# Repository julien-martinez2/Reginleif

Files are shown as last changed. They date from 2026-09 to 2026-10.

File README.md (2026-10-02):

# 🕷️ Reginleif — Autonomous Quadruped Walking Robot


[]()
[]()
[]()


> A custom-engineered, distributed quadruped combat walker inspired by the **XM2 Reginleif** and **M1A4 Juggernaut** from the acclaimed light novel & anime series ***86 - Eighty Six***.

---

## 📖 Table of Contents

- [Motivation & Inspiration](#-motivation--inspiration)
- [System Architecture](#-system-architecture)
  - [Functional Architecture](#functional-architecture)
  - [Technical & Electrical Architecture](#technical--electrical-architecture)
- [Hardware & Key Components](#-hardware--key-components)
  - [Sun Board (Central Controller)](#sun-board)
  - [Planet Boards (Legs Controllers)](#planet-boards)
  - [Moon Boards (Angle Sensors)](#moon-boards)
  - [Dual-Encoder Sensing Strategy](#dual-encoder-sensing-strategy)
- [Firmware Architecture](#-firmware-architecture)
  - [NVIC Preemptive Priority Hierarchy](#nvic-preemptive-priority-hierarchy)
  - [Real-Time Timer Scheduling](#real-time-timer-scheduling)
  - [Zero-CPU UART DMA with IDLE Line Detection](#zero-cpu-uart-dma-with-idle-line-detection)
- [Project Documentation & CAD Assets](#-project-documentation--cad-assets)
- [Roadmap & Deliverables](#-roadmap--deliverables)
- [Author & Community](#-author--community)
- [License](#-license)

---

## 💡 Motivation & Inspiration

The goal of this project is to take the agility, distinctive gait mechanics, and rugged aesthetic of the **XM2 Reginleif** from *86 - Eighty Six* and bring it into physical reality.

Building a multi-jointed legged walker from scratch serves as an end-to-end engineering challenge across multiple disciplines:
1. **Developing Real-Time Embedded Skills:** Mastering bare-metal ARM Cortex-M control, deterministic task scheduling, multi-bus SPI synchronization, and DMA streaming.
2. **Custom PCB & Power Electronics:** Designing compact 4-layer PCBs, handling thermal dissipation, power distribution for 16 simultaneous DC gearmotors, and integrated eFuse circuit protection.
3. **Complex Kinematics & Robotics:** Solving 3D inverse kinematics, gait generation, and closed-loop position control with mechanical backlash compensation.

**Open Source Philosophy:** Advanced quadruped robotics often relies on expensive off-the-shelf smart actuators or proprietary platforms. By documenting every schematic, trade-off, calculation, and line of code, this repository aims to serve as a practical, open reference for robotics students, engineers, and hobbyists building their own legged systems.

---

## 🏛️ System Architecture

### Functional Architecture

The robot employs a **hierarchical distributed architecture**, offloading high-frequency motor control to dedicated microcontrollers while centralizing planning, telemetry, and stabilization:

```
                      ┌────────────────────────────────────────┐
                      │        High-Level Intelligence         │
                      │     Raspberry Pi (Vision, Autonomy)    │
                      └──────────────────┬─────────────────────┘
                                         │ SPI / UART
                                         ▼
                      ┌────────────────────────────────────────┐
                      │    Central Master MCU ("Sun Board")    │
                      │  • IMU Body Stabilization (BNO086)     │
                      │  • Power Distribution & Battery Monitor│
                      │  • Master Gait Coordinator             │
                      └──────────────────┬─────────────────────┘
                                         │
          ┌──────────────────────────────┼──────────────────────────────┐
          │ RS-485 Differential Bus      │ (Master-Slave Protocol)      │
          ▼                              ▼                              ▼
 ┌──────────────────┐           ┌──────────────────┐           ┌──────────────────┐
 │  Planet Board 1  │           │  Planet Board 2  │           │ Planet Boards 3-4│
 │ (STM32G031)      │           │ (STM32G031)      │           │  (STM32G031)     │
 │ 4x N20 Motors    │           │ 4x N20 Motors    │           │ 4x N20 Motors    │
 └──────────────────┘           └──────────────────┘           └──────────────────┘
          │                     SPI Bus  │ (Master-Slave Protocol)      │
          ▼                              ▼                              ▼
 ┌──────────────────┐           ┌──────────────────┐           ┌──────────────────┐
 │ Moon Boards 1-4  │           │ Moon Boards 5-8  │           │ Moon Boards 9-16 │
 │ (MA730 Abs.)     │           │ (MA730 Abs.)     │           │ (MA730 Abs.)     │
 └──────────────────┘           └──────────────────┘           └──────────────────┘

```

---

### Technical & Electrical Architecture

```
                              [ 3S LiPo Battery (11.1V - 12.6V) ]
                                              │
                                              ▼
                                 [ TPS259827 15A eFuse ]
                                (UVLO Cutoff at 10.83V)
                                              │
                  ┌───────────────────────────┼───────────────────────────┐
                  │ VM (12V) Motor Power      │                           │
                  ▼                           ▼                           ▼
        ┌───────────────────┐       ┌───────────────────┐       ┌──────────────────────┐
        │ AP63205 (5V Buck) │       │ AP63203 (3.3V)    │       │ TPS22919 Load SW     │
        │ -> Raspberry Pi   │       │ -> Sun Board MCU  │       │ -> Planet Board VDD  │
        └───────────────────┘       └───────────────────┘       └─────────┬────────────┘
                                                                          │
                                  ┌───────────────────────────────────────┘
                                  │ 5-Pin JST-PA Harness (12V, 3.3V, GND, RS485_A/B)
                                  ▼
         ┌─────────────────────────────────────────────────────────────────┐
         │                     MODULAR PLANET BOARD (x4)                   │
         │                                                                 │
         │   [ THVD1406 RS-485 ] <── UART DMA ──> [ STM32G031 MCU ]        │
         │                                              │                  │
         │              ┌───────────────────────────────┴────────┐         │
         │              ▼ (SPI1 Bus)                             ▼ (SPI2)  │
         │     [ 4x MA730 Encoders ]                       [ DRV8908 ]     │
         │     Absolute Joint Angles                   8x Half-Bridges     │
         │     (Diametric Magnets)                               │         │
         │              ▲                                        ▼         │
         │              │ Joint Output Shaft              4x CHF-GW12T-N20 │
         │              └──────────────────────────────── (302:1 Worm)     │
         │                                                       │         │
         │   [ Incremental Encoders ] <── EXTI (PA0, PB1, PB3, PC14) ─────┘│
         └─────────────────────────────────────────────────────────────────┘

```

---

## 🛠️ Hardware & Key Components

### Sun Board
- **Master Processing:** STM32G031 / Raspberry Pi pairing for autonomous operation, telemetry streaming, and wireless communication.
- **Power & Circuit Protection:**
  - **TPS259827 15A eFuse:** Ultra-fast short-circuit protection and hardware programmable undervoltage lockout (V_UVLO = 10.83 V), preventing 3S LiPo over-discharge).
  - **AP63205 & AP63203:** High-efficiency synchronous buck converters generating 5 V (logic/SBC) and 3.3 V (peripherals).
  - **TPS22919 Load Switches:** Independent hardware-level logic power isolation and current limiting for each peripheral board.
- **Inertial Measurement:** **BNO086** 9-axis sensor fusion IMU over SPI for real-time body attitude stabilization.

### Planet Boards
- **Dedicated MCU:** **STM32G031G8U6** (ARM Cortex-M0+ running at 16 MHz, 4-layer compact layout with solid internal ground planes).
- **Motor Driver:** **DRV8908** automotive-grade 8 half-bridge driver, providing 4 fully independent bi-directional motor channels with individual hardware current limiting and fault telemetry.
- **Bus Transceiver:** **THVD1406DR** RS-485 transceiver with auto-direction sensing, eliminating the need for half-duplex DE/RE switching overhead.
- **Connectors:** JST-PA (power and differential communication) and JST-ZH (motor and sensor interconnects).

### Moon Boards
- **Angle Sensor:** MA730 is a magnetic angle sensor, which is placed next to the shaft of the motor on which a magnet is put.
- **Connectors:** JST-ZH (same as the motors).

---

### Dual-Encoder Sensing Strategy

Miniature worm gearboxes provide high stall torque and self-locking capabilities, but introduce mechanical backlash. To solve this, a dual-encoder feedback architecture is implemented:

| Sensor Type | Part & Interface | Resolution | Placement | Role in Control Loop |
| :--- | :--- | :--- | :--- | :--- |
| **Incremental Magnetic Encoder** | 2-Phase Hall (EXTI) | 2x Quadrature (~2107 counts/rev on motor shaft) | Motor Tail Shaft | **High-frequency velocity estimation** and instantaneous PID rate control. |
| **Absolute Magnetic Encoder** | **MA730GQ-Z** (SPI1) | 14-bit (16,384 counts/rev) | Output Joint Shaft (with Diametric Ring Magnets) | **Absolute angle calibration (10 Hz)** to eliminate gearbox play, backlash, and drift. |

---

## 💻 Firmware Architecture

### NVIC Preemptive Priority Hierarchy

The Cortex-M0+ interrupt controller is prioritized to guarantee that critical hardware signals and high-speed encoder transitions are never delayed by slower math computations:

```

Priority 0 (Highest) ──► SysTick & EXTI Lines (PA0, PB1, PB3, PC14, PA2 nFAULT)
│
Priority 1             ──► USART1 Communication & DMA Channels
│
Priority 2             ──► TIM2 (DRV8908 SPI Updates) & TIM3 (MagAlpha SPI Reads)
│
Priority 3 (Lowest)    ──► TIM1 (Software Inverse Kinematics & PID Loops)

```

- **Zero-Jitter Pulse Counting:** Encoders run at Priority 0 so wheel pulses are captured without dropped ticks during motor acceleration.
- **Fault Handling:** The open-drain `nFAULT` pin on `PA2` triggers an immediate shutdown sequence on overcurrent or thermal warnings.
- **Safe Preemption:** Heavy inverse kinematics floating-point calculations (Priority 3) safely yield execution whenever a peripheral event occurs.

---

### Real-Time Timer Scheduling

| Timer | Execution Frequency | Period | Task Description |
| :--- | :--- | :--- | :--- |
| **EXTI Lines** | Asynchronous | < 1 µs | Hardware edge-triggered incremental encoder decoding (Motors 1–4). |
| **TIM3** | **10 Hz** | 100 ms | SPI1 sequential polling of the 4 joint-level MA730 absolute encoders. |
| **TIM2** | **50 Hz** | 20 ms | SPI2 multi-channel register write updating DRV8908 motor PWM/directions. |
| **TIM1** | **20 Hz - 50 Hz** | 20 - 50 ms | Inverse kinematics trajectory solving, PID position/velocity loop execution. |

---

### Zero-CPU UART DMA with IDLE Line Detection

Communication between the central master board and the leg modules uses DMA combined with hardware IDLE line detection (`HAL_UARTEx_ReceiveToIdle_DMA`):

```cpp
// Non-blocking packet reception
void HAL_UARTEx_RxEventCallback(UART_HandleTypeDef *huart, uint16_t Size) {
    if (huart->Instance == USART1) {
        // Validate header and packet checksum
        if (Size >= 11 && rx_buffer[0] == 0xAA && rx_buffer[1] == 0x55) {
            ParseMasterCommand(rx_buffer, Size);
        }
        // Immediately re-arm DMA reception for the next packet
        HAL_UARTEx_ReceiveToIdle_DMA(&huart1, rx_buffer, RX_BUFFER_SIZE);
    }
}

```

* **Zero CPU overhead** while bytes are on the wire.
* The MCU triggers a single interrupt only after an entire variable-length packet is delivered and the bus goes idle.

---

## 📂 Project Documentation & CAD Assets

All schematics, BOMs, mechanical studies, and test records are available in the repository:

* **Hardware Schematics & KiCad Layouts:** 4-layer Leg Board, Satellite Angle Sensor PCBs, and Central Carrier Board.
* **Mechanical CAD:** 3D printed joint housings, worm gearbox mounts, and chassis brackets.

---

## 🗺️ Roadmap & Deliverables

* [x] Functional specification and torque/power feasibility study
* [x] 4-layer Leg Board PCB design and component assembly (KiCad)
* [ ] Mechanical Design and 3D-printing (FreeCAD)
* [ ] Bare-metal firmware setup (CubeMX, SPI1/SPI2, multi-channel EXTI, UART DMA)
* [ ] MA730 absolute magnetic sensor driver (`magalpha.cpp`)
* [ ] DRV8908 8 half-bridge motor controller driver (`drv8908.cpp`)
* [ ] 3D Inverse Kinematics math library and body orientation matrix
* [ ] Dynamic walking gait generation (Crawl, Trot, and Creep gaits)
* [ ] Central Sun Board assembly & BNO086 IMU stabilization loop
* [ ] Auxiliary subsystems: Tilt-axis turret mechanism and deployable anchor system

---

## 👤 Author & Community

Designed and engineered with passion by **Julien Martinez** ([@julien-martinez2](github.com/julien-martinez2)).

If you are working on custom quadruped walkers, legged robotics, or distributed motor controllers, feel free to open an issue, start a discussion, or contribute!

---

## 📄 License

This project is distributed under the **MIT License**. See [`LICENSE`](https://www.google.com/search?q=LICENSE) for more details.

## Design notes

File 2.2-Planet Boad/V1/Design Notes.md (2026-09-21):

# Planet Board V1 Design Notes

This board is designed to control 4 motors and get both their displacement with high-precision and absolute position.

The Planet Board has components on both sides, with power on top and logic on bottom.

To have this, all components are SMD.

### Power Supply

There is no power conversion in the Planet Boards, both the high and low voltage come from the Sun Board. This is to make the architecture easier and PCB surface smaller, even if this reduces the modularity of the board.

This works because the distance between the boards is very short, if it were important the voltage drop on the 3.3V rail would prevent this architecture.

### STM32

The model used is a STM32G031G8U6.

The specifications of this model has are : 

6 timers

2 SPI bus

2 UART bus

Real-Time Clock

28 pins including 26 GPIO and 15 ADC channels

14 External Interrupts (not on all pins) with 4 levels

Low-power modes

64 MHz CPU frequency

A useful function of STM32s here is that they can program, reset and boot each other via UART.

The Sun Board still includes a 4-pin header to program via SWD

Finally, some pins are compatible with 5V (reception only), which are nice to make the architecture even more modular.

### Sun Board Connexion

The Planet Boards don't include a resistor because of the topology, but also to make the legs as simple as Plug \& Play.

The connectors used are the same as in the Sun Board, JST-PA with reinforcement.

### Motors

The motors used in the first version of the project are CHF-GW12T-N20VA, N20 motors with worm gearboxes and incremental encoders.

The motors come with JST-ZH connectors, so the same are used on the PCB.

These motors stall at 0.4A (3.0kg/cm), and are rated at 0.15A (0.9kg.cm). Their nominal voltage is 12V for power and 3.3V or 5V for the encoders.

### Motors Driver

The motors driver used is a DRV8908, which can control up to 8 Half-Bridge (4 DC motors).

The rated current and voltage for each channel is much higher than the PCBs and the motors themselves at 1A per channel, and up to 40V.

It has a low-power mode, same as the STM32, though it can't control the HBs in this state.

The interface with the STM32 is an SPI bus.

The minimum PWM frequency for N20 motors is 400 Hz and the DRV is able to generate 2000 Hz

Finally, it has an nFAULT pin and an Open-Load Detection which monitor the motors state.

It also has undervoltage, overvoltage and overcurrent protection but these won't be useful here.

### Absolute Encoders

Since the motors only have incremental encoders, an absolute encoder is used to update the absolute position regularly.

This absolute encoder is put on the Moon Board which is placed right next to the motor shaft, improving modularity in case the motor model is changed.

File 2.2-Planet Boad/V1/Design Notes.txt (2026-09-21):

Sun Board V1 Design Notes

This board is designed to distribute power and supervise up to 5 Planet Boards by communicating via UART.
It has an SPST switch to power ON/OFF the whole robot.

Power Supply
The maximum voltage in the robot is 12.6V (LiPo 3S battery), so all the components on the power rail are rated for 25V or more.

The maximum current pulled by the robot is around 8A (considering that all the motors are stalling, which shouldn't happen and some software protections will be used). 
The Sun Board can handle up to 15A on the power rail, 2A for the 5V rail (RPI) and 2A for the 3.3V rail.

The eFuse used is a TPS259827, with the following configuration:
Undervoltage protection at 11V to protect the battery
Circuit Breaker at 15A
Current monitoring giving analog value from 0 to 2.97V (0 to 15A)
Lowest slew rate (0.68V/ms)

STM32
The model used is a STM32G031G8U6, same as the Planet Boards to keep the BOM consistent.
The specifications of this model has are : 
6 timers
2 SPI bus
2 UART bus
Real-Time Clock
28 pins including 26 GPIO and 15 ADC channels
14 External Interrupts (not on all pins) with 4 levels
Low-power modes
64 MHz CPU frequency

A useful function of STM32s here is that they can program, reset and boot each other via UART.

The Sun Board still includes a 4-pin header to program via SWD

Finally, some pins are compatible with 5V (reception only), which are nice to make the architecture even more modular.

Planet Board Connexion
The Sun Board is connected to the Planet Boards via 5 wires :
- 3.3V
- VCC
- GND
- TX
- RX

Since each Planet Board can pull up to 2A, the connectors and wires are sized for a 3A constant load.

The Sun Board's STM32 communicates with the Planet Boards' STM32s via UART.
Only one resistor is used on the Sun Board to keep a modular structure and since the architecture is closer to a Star topology than a Chain one 

BNO085
To balance the robot, a BNO085 is used as is has almost no drift.
The communication to the STM32 is done via SPI bus.

RPI Zero 2 W
The RPI handles the communication to the computer and camera feedback.
It rests on a female pin header and M2 standoffs and communicates with the STM32 via UART.

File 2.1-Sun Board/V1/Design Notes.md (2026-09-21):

# Sun Board V1 Design Notes

This board is designed to distribute power and supervise up to 5 Planet Boards by communicating via UART.

It has an SPST switch to power ON/OFF the whole robot.

The Sun Board has components on both sides, same as the Planet Board, with logic on top and power on bottom.

To have this, all components are SMD, apart from the battery connector which is soldered manually in a hole.

### Power Supply

The maximum voltage in the robot is 12.6V (LiPo 3S battery), so all the components on the power rail are rated for 25V or more.

The maximum current pulled by the robot is around 8A (considering that all the motors are stalling, which shouldn't happen and some software protections will be used). 

The Sun Board can handle up to 15A on the power rail, 2A for the 5V rail (RPI) and 2A for the 3.3V rail.

The eFuse used is a TPS259827, with the following configuration:

* Undervoltage protection at 11V to protect the battery
* Circuit Breaker at 15A
* Current monitoring giving analog value from 0 to 2.97V (0 to 15A)
* Lowest slew rate (0.68V/ms)

### STM32

The model used is a STM32G031G8U6, same as the Planet Boards to keep the BOM consistent.

The specifications of this model has are : 

* 6 timers
* 2 SPI bus
* 2 UART bus
* Real-Time Clock
* 28 pins including 26 GPIO and 15 ADC channels
* 14 External Interrupts (not on all pins) with 4 levels
* Low-power modes
* 64 MHz CPU frequency

A useful function of STM32s here is that they can program, reset and boot each other via UART.

The Sun Board still includes a 4-pin header to program via SWD

Finally, some pins are compatible with 5V (reception only), which are nice to make the architecture even more modular.

### Planet Board Connexion

The Sun Board is connected to the Planet Boards via 5 wires :

\- 3.3V

\- VCC

\- GND

\- TX

\- RX

Since each Planet Board can pull up to 2A, the connectors and wires are sized for a 3A constant load.

The connector used are JST-PA with reinforcement.

The Sun Board's STM32 communicates with the Planet Boards' STM32s via UART.

Only one resistor is used on the Sun Board to keep a modular structure and since the architecture is closer to a Star topology than a Chain one

### BNO085

To balance the robot, a BNO085 is used as is has almost no drift.

The communication to the STM32 is done via SPI bus.

### RPI Zero 2 W

The RPI handles the communication to the computer and camera feedback.

It rests on a female pin header and M2 standoffs and communicates with the STM32 via UART.

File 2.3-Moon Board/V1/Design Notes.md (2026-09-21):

# Moon Board V1 Design Notes

This board is designed to get the absolute position of a single motor shaft. It sits right next to it on the motor in a side-shaft configuration (possible because they have worm gearboxes).

The components are only on one side and the PCB is basic, but to fabricate it along with the Sun and Planet boards it also has 4 layers.

### Connectors

The same connectors as the motors are used between the Planet and Moon board to simplify the BOM.

### Absolute Encoders

The absolute encoders used in this project are MagAlpha, an angle sensor measuring the magnetic field generated by a magnet fixed on the other side of the joint (so the shaft here).

The magnet is a diametric ring magnet, put on the joint around the shaft.

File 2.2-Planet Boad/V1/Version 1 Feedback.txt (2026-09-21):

Planet Board Version 1 

Goals: 
- The main goal of this board is to be able to control a whole leg with close control (4 motors and 4 angle sensors).
- The second goal is to make this board modular, which can be used in various robots (ie. RC car, drone, etc.).
- The third goal is to make the board as small as possible.

Feedback:
- The board lacks mounting pins
- The board lacks LEDs to show its state (3.3V, VCC, Motor driver fault)
- Lacks more silkscreen to avoid having to look at design files
- Lacks some protections (Local PTC fuse, TVS diode)
- Put two of the angle sensors (currently on the moon boards) directly on the planet board
- Add test pins since the chosen connectors can't be gripped, and even more the STM32
- Too many vias near the center of the board
- Power spread on the PCB

Most of these issues come from trying to make the board smaller.

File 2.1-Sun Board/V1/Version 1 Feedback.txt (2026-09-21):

Sun Board Version 1 

This board was designed after the Planet and Moon ones, and already resolves some of their issues.

Goals: 
- The main goal of this board is to be able to supervise up to 5 Planet Boards.
- The second goal is to make this board modular, which can be used in various robots (ie. RC car, drone, etc.).
- The third goal is to make the board as small as possible, but still big enough for an RPI Zero 2 W to fit on.

Feedback:
- The board uses the same mounting pins for the RPI and the mechanical structure
- The board lacks LEDs to show its state (3.3V, VCC, Planet Board load)
- Lacks more silkscreen to avoid having to look at design files
- Add test pins since the chosen connectors can't be gripped, so mainly the STM32, BNO085/86 and some connectors
- The chosen SPDT switch is too small

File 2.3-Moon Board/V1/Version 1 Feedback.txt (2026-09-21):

Moon Board Version 1 

Most of the goals and feedbacks of this board are the same as the Planet Board since they were both designed together.
I will only keep here what will be relevent after taking into account the feedback for the Planet Board.

Goals: 
- The main goal of this board is to be able to get the absolute angle of a motor shaft via a diametric ring magnet in side-shaft position.
- The second goal is to make this board modular, which can be used in various robots (ie. RC car, drone, etc.).
- The third goal is to make the board as small as possible.

Feedback:
- The board lacks mounting pins
- The board lacks LEDs to show its state (3.3V, VCC, Motor driver fault)
- Lacks more silkscreen to avoid having to look at design files
- Lacks some protections (Local PTC fuse, TVS diode)
- Add test pins since the chosen connectors can't be gripped, so only the MagAlpha here

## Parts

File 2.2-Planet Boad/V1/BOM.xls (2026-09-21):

PCBWay Bom Quotation, Product No.:
Item # | *Designator | *Qty | Manufacturer | *Mfg Part # | Description / Value | *Package/Footprint | Mounting Type | Your Instructions / Notes | *Unit Price(5 units) | *Total | *Delivery Time | *Actual Purchase Mfg Part # | *PCBWay Note | Customer Reply | PCBWay Update
1 | J1 | 5 | JST | SM05B-PASS-TBT | Connector Header Surface Mount, Right Angle 5 position 0.079" (2.00mm) | SMT 5P | SMD | Digikey or Chinese equivalent |  | $0.000
2 | J2 | 5 | Harwin | M20-7910442R | 4 Position Receptacle Connector 0.100 (2.54mm) Surface Mount, Right Angle Gold | SMT 4P | SMD | Digikey or Chinese equivalent |  | $0.000
3 | J3,J4,J5,J6,J7,J8,J9,J10 | 40 | JST | S6B-ZR-SM4A-TF | Connector Header Surface Mount, Right Angle 6 position 0.059 (1.50mm) | SMT 6P | SMD | Digikey or Chinese equivalent |  | $0.000
4 | U1 | 5 | STMicroelectronics | STM32G031G8U6 | ARM® Cortex®-M0+ STM32G0 Microcontroller IC 32-Bit 64MHz 64KB (64K x 8) FLASH 28-UFQFPN (4x4) | UFQFPN-28 | SMD | Digikey or Chinese equivalent |  | $0.000
5 | U2 | 5 | Texas Instruments | DRV8908QPWPRQ1 | Half Bridge (8) Driver DC Motors, General Purpose MOSFET (Metal Oxide) 24-HTSSOP | HTSSOP-24 | SMD | Digikey or Chinese equivalent |  | $0.000
6 | U3 | 5 | Texas Instruments | THVD1406DR | 1/1 Transceiver Half RS422, RS485 8-SOIC | SOIC | SMD | Digikey or Chinese equivalent |  | $0.000
8 | R1 | 5 | Panasonic | ERA-3ARW103V | RES, 10.0 k, 0.05%, 0.1 W, AEC-Q200 Grade 0, 0603 | 0603 | SMD | Digikey or Chinese equivalent |  | $0.000
9 | C5 | 5 | KEMET | T491X107K025AT | CAP, AL, 100 µF, 25 V, +/- 10%, 0.3 ohm, 2917 X SMD | CASE-X-7343-43 | SMD | Digikey or Chinese equivalent |  | $0.000
10 | C1 | 5 | Samsung | CL10B105KQ8NNNC | CAP, CERM, 1 uF, 6.3 V, +/- 10%, X7R, 0603 | 0603 | SMD | Digikey or Chinese equivalent |  | $0.000
11 | C2,C6,C7 | 15 | KEMET | C0603C104K9RAC7867 | CAP, CERM, 0.1 µF, 6.3 V,+/- 10%, X7R, 0603 | 0603 | SMD | Digikey or Chinese equivalent |  | $0.000
12 | C3,C4 | 10 | KEMET | C0603C104J5RACTU | CAP, CERM, 0.1 uF, 50 V, +/- 5%, X7R, 0603 | 0603 | SMD | Digikey or Chinese equivalent |  | $0.000
 |  |  |  |  |  |  |  |  | Component Cost | $0.00
 |  |  |  |  |  |  |  |  | Assembly Cost
 |  |  |  |  |  |  |  |  | PCB Cost
 |  |  |  |  |  |  |  |  | All Total 5 Units

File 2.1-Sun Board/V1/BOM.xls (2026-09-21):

PCBWay Bom Quotation, Product No.:
Item # | *Designator | *Qty | Manufacturer | *Mfg Part # | Description / Value | *Package/Footprint | Mounting Type | Your Instructions / Notes | *Unit Price(5 units) | *Total | *Delivery Time | *Actual Purchase Mfg Part # | *PCBWay Note | Customer Reply | PCBWay Update
1 | R1 | 1 | Würth Elektronik | 560112110033 | 1 MOhms ±1% 0.1W, 1/10W | SMD 0402 | SMD
2 | R2 | 1 | Würth Elektronik | 560112110190 | 113 kOhms ±1% 0.1W, 1/10W | SMD 0402 | SMD
3 | R3,R10 | 2 | Würth Elektronik | 560112110019 | 100 kOhms ±1% 0.1W, 1/10W | SMD 0402 | SMD
4 | R11 | 1 | YAGEO | RT0402BRD0733KL | 33 kOhms ±0.1% 0.063W, 1/16W | SMD 0402 | SMD
5 | R6,R8,R9 | 3 | Panasonic Industry | ERA-3ARW103V | 10 kOhms ±0.05% 0.1W, 1/10W | SMD 0603 | SMD
6 | R5 | 1 | Würth Elektronik | 560112110108 | 806 Ohms ±1% 0.1W, 1/10W | SMD 0402 | SMD
7 | R7 | 1 | Würth Elektronik | 560112110065 | 120 Ohms ±1% 0.1W, 1/10W | SMD 0402 | SMD
8 | R4 | 1 | Würth Elektronik | 560112110008 | 100 Ohms ±5% 0.1W, 1/10W | SMD 0402 | SMD
9 | C4,C5 | 2 | KEMET | T491X107K025AT | 100uF, 25V, 10% Tolerance | SMD 2917-X | SMD
10 | C13,C14,C17,C18,C19 | 5 | Samsung Electro-Mechanics | CL21A226KOQNNNG | 22 µF ±10% 16V Ceramic Capacitor X5R | SMD 0805 | SMD
11 | C11,C15 | 2 | Murata Electronics | GRT188R61E106ME13D | 10 µF ±20% 25V Ceramic Capacitor X5R | SMD 0603 | SMD
12 | C20,C21,C22,C23,C24 | 5 | Samsung Electro-Mechanics | CL05A105KO5NNNC | 1 µF ±10% 16V Ceramic Capacitor X5R | SMD 0402 | SMD
13 | C1,C2,C3,C7,C8,C9,C10,C12,C16,C25 | 10 | KEMET | C0603C104J5RACTU | 0.1 µF ±5% 50V Ceramic Capacitor X7R | SMD 0603 | SMD
14 | C6 | 1 | YAGEO | CC0402JRX7R9BB682 | 6800 pF ±5% 50V, X7R | SMD 0402 | SMD
15 | L1,L2 | 2 | Würth Elektronik | 74438357047 | 4.7 µH Shielded Molded Inductor 5.1 A 44mOhm Max | SMD 1616 | SMD
16 | J1 | 1 | Harwin Inc. | M20-7910442R | 4 Position Receptacle Connector 0.100" (2.54mm) | 4POS | SMD
17 | J2,J3,J4,J5,J6 | 5 | JST | SM05B-PASS-TBT | 5-pin, SMD, Right-Angle | 5POS | SMD
18 | J7 | 1 | Sullins Connector Solutions | NPTC202KFMS-RC | 40 Position Header Connector 0.100" (2.54mm) | 40POS | SMD
19 | S1 | 1 | E-Switch | EG1215AA | SWITCH SLIDE SPDT 25MA 24V | SMD, Right-Angle | SMD
20 | U1 | 1 | STMicroelectronics | STM32G031G8U6 | ARM® Cortex®-M0+ STM32G0 Microcontroller IC 32-Bit 64MHz 64KB (64K x 8) FLASH 28-UFQFPN (4x4) | SMD UFQFPN-28 | SMD
21 | U2 | 1 | Texas Instruments | TPS259824ONRGET | Electronic Fuse Regulator 15A | SMD 24-VQFN | SMD
22 | U3 | 1 | Texas Instruments | THVD1406DR | 1/1 Transceiver Half RS422, RS485 | SMD 8-SOIC | SMD
23 | U4 | 1 | CEVA Technologies, Inc. | BNO086 | Accelerometer, Gyroscope, Magnetometer, Temperature, 9 Axis Sensor I2C, SPI Output | SMD 28-TFLGA | SMD
24 | U5 | 1 | Diodes Incorporated | AP63203WU | Buck Switching Regulator IC Positive Fixed 3.3V 1 Output 2A | SMD TSOT23-6 | SMD
25 | U6 | 1 | Diodes Incorporated | AP63205WU | Buck Switching Regulator IC Positive Fixed 5V 1 Output 2A | SMD TSOT23-6 | SMD
26 | U7,U8,U9,U10,U11 | 5 | Texas Instruments | TPS22919DCKR | Power Switch/Driver 1:1 N-Channel 1.5A | SMD SC-70-6 | SMD
26
27
 |  |  |  |  |  |  |  |  | Component Cost | $0.00
 |  |  |  |  |  |  |  |  | Assembly Cost
 |  |  |  |  |  |  |  |  | PCB Cost
 |  |  |  |  |  |  |  |  | All Total 5 Units

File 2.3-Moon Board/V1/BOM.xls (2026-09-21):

PCBWay Bom Quotation, Product No.:
Item # | *Designator | *Qty | Manufacturer | *Mfg Part # | Description / Value | *Package/Footprint | Mounting Type | Your Instructions / Notes | *Unit Price(5 units) | *Total | *Delivery Time | *Actual Purchase Mfg Part # | *PCBWay Note | Customer Reply | PCBWay Update
3 | J11 | 1 | JST | S6B-ZR-SM4A-TF | Connector Header Surface Mount, Right Angle 6 position 0.059 (1.50mm) | SMT 6P | SMD | Digikey or Chinese equivalent |  | $0.000
7 | U4 | 1 | MPS | MA730GQ-P | Hall Effect Sensor Angle External Magnet | QFN-16 | SMD | Digikey or Chinese equivalent |  | $0.000
10 | C8 | 1 | Samsung | CL10B105KQ8NNNC | CAP, CERM, 1 uF, 6.3 V, +/- 10%, X7R, 0603 | 0603 | SMD | Digikey or Chinese equivalent |  | $0.000
 |  |  |  |  |  |  |  |  | Component Cost | $0.00
 |  |  |  |  |  |  |  |  | Assembly Cost
 |  |  |  |  |  |  |  |  | PCB Cost
 |  |  |  |  |  |  |  |  | All Total 5 Units

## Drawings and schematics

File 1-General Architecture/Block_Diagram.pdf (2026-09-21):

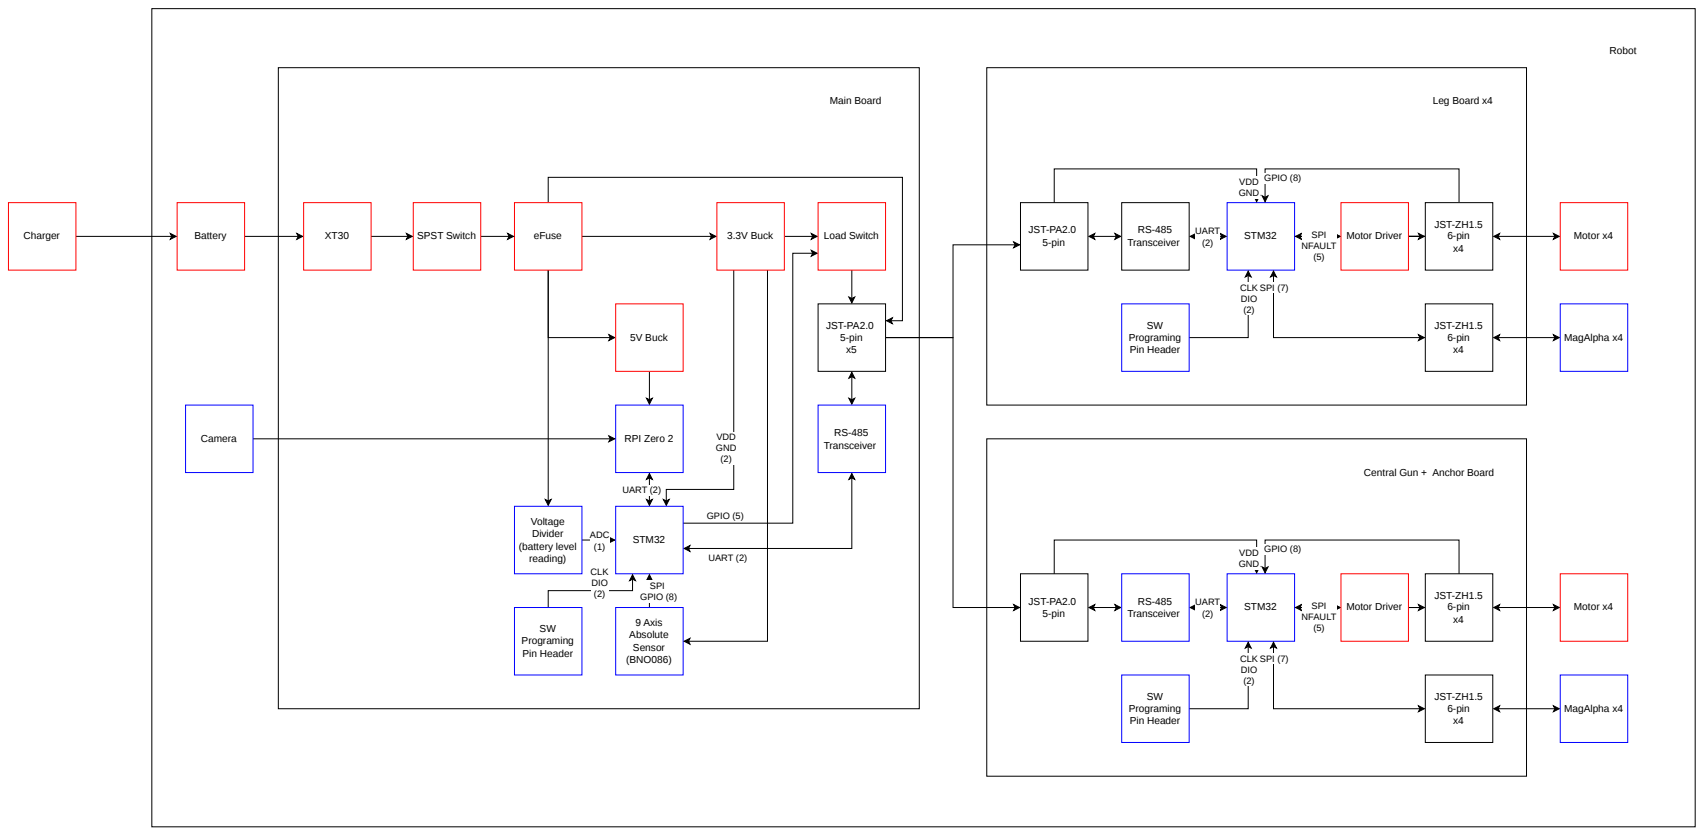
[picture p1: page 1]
Battery; eFuse; ADC (1); Voltage Divider (battery level reading); UAR; GPIO (5); VDD GND (2); STM32; JST-PA2.0 5-pin x5; Main Board; JST-PA2.0; 5-pin; SPI; NFAULT (5); GPIO (8); JST-ZH1.5 6-pin x4; Leg Board x4; Motor x4; VDD GND; RPI Zero 2; SPI GPIO (8); 9 Axis Absolute Sensor (BNO086); Camera; SPI (7); MagAlpha x4; Transceiver; Motor Driver; 5V Buck; RS-485 Transceiver; Charger; 3.3V Buck; CLK DIO (2); SW Programing Pin Header; SPST Switch; Robot; Load Switch

Central Gun + Anchor Board

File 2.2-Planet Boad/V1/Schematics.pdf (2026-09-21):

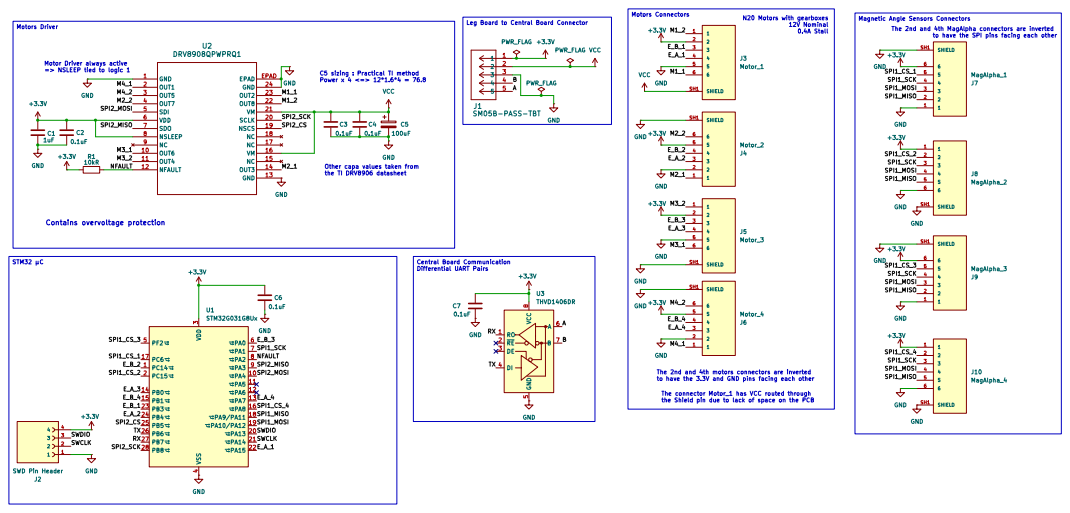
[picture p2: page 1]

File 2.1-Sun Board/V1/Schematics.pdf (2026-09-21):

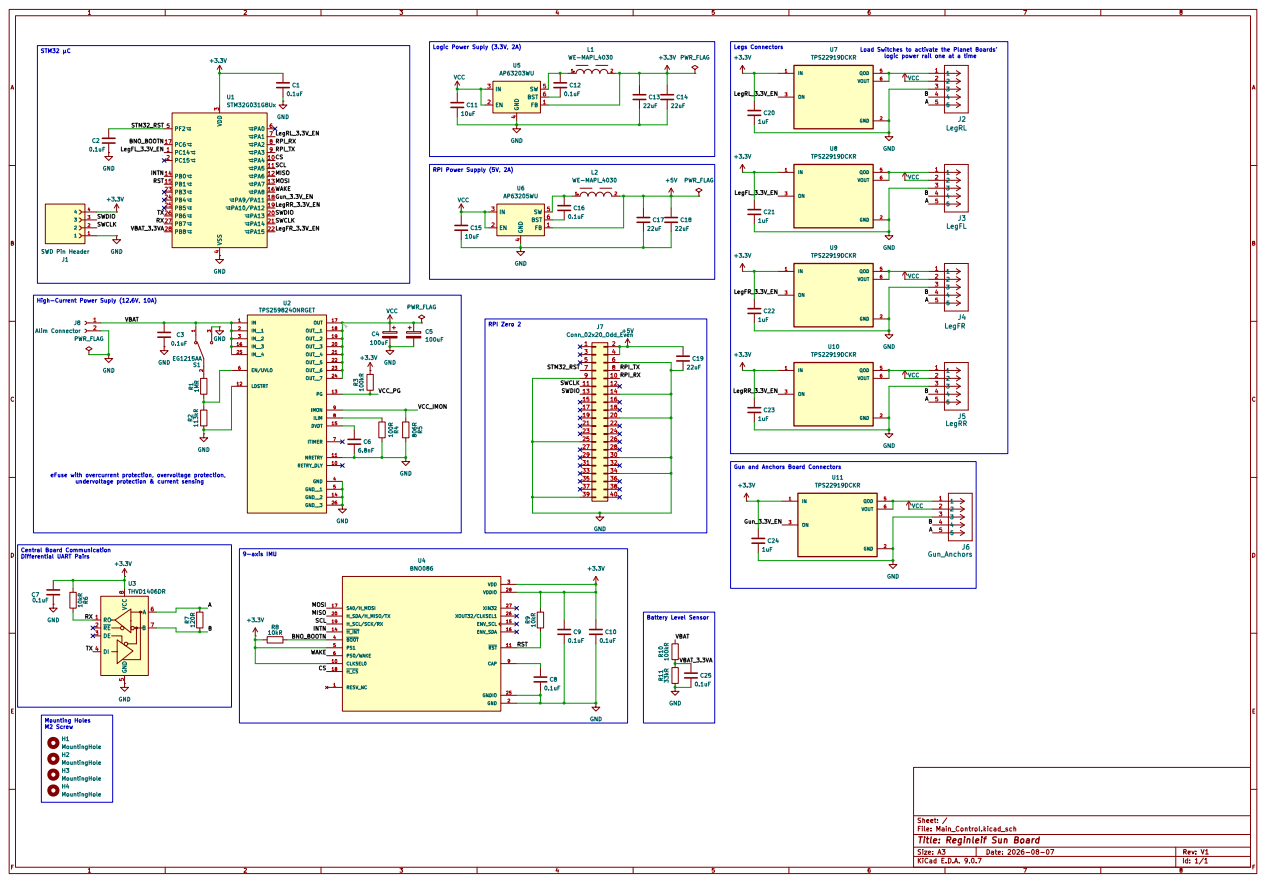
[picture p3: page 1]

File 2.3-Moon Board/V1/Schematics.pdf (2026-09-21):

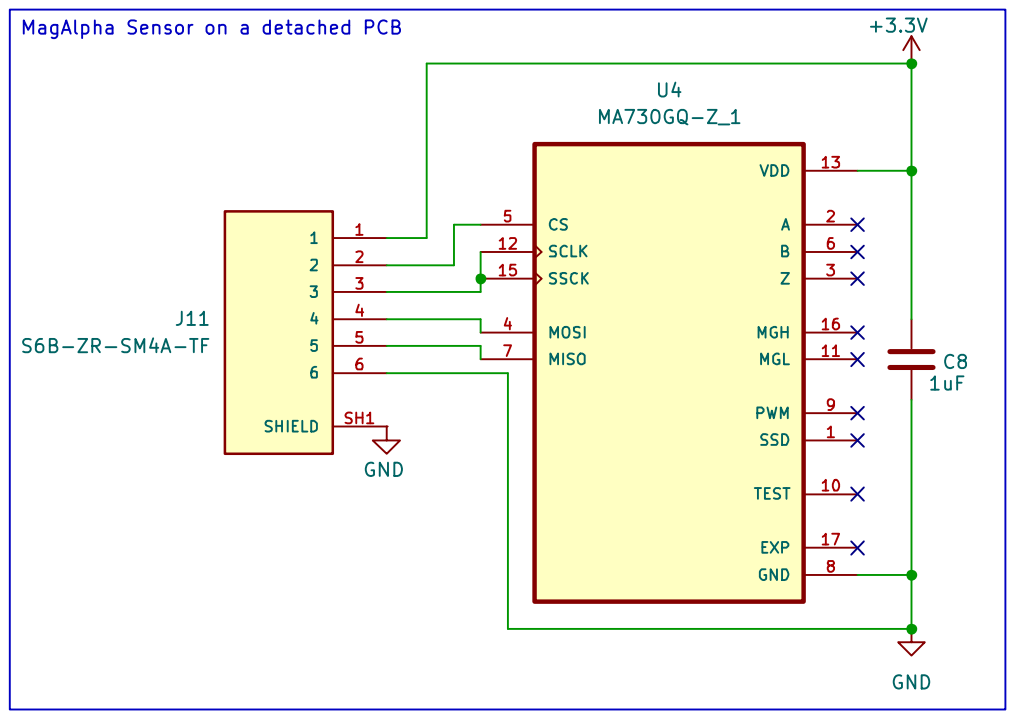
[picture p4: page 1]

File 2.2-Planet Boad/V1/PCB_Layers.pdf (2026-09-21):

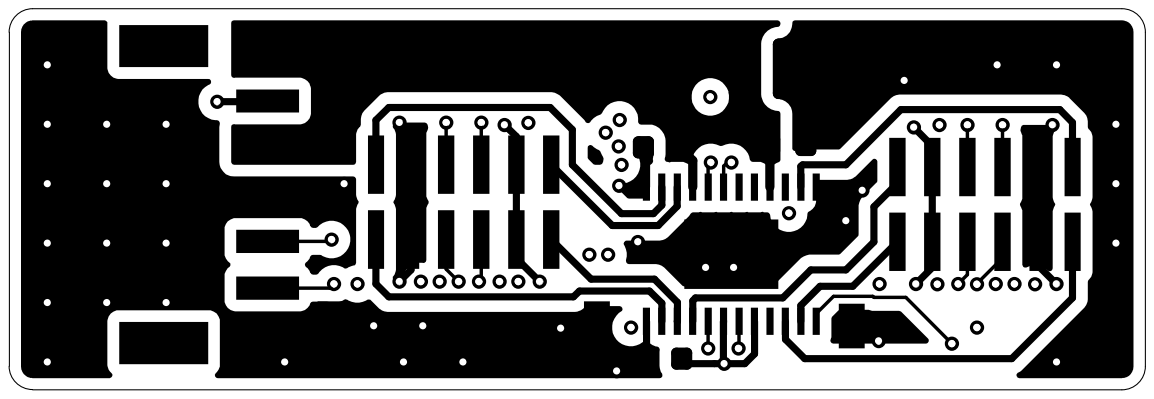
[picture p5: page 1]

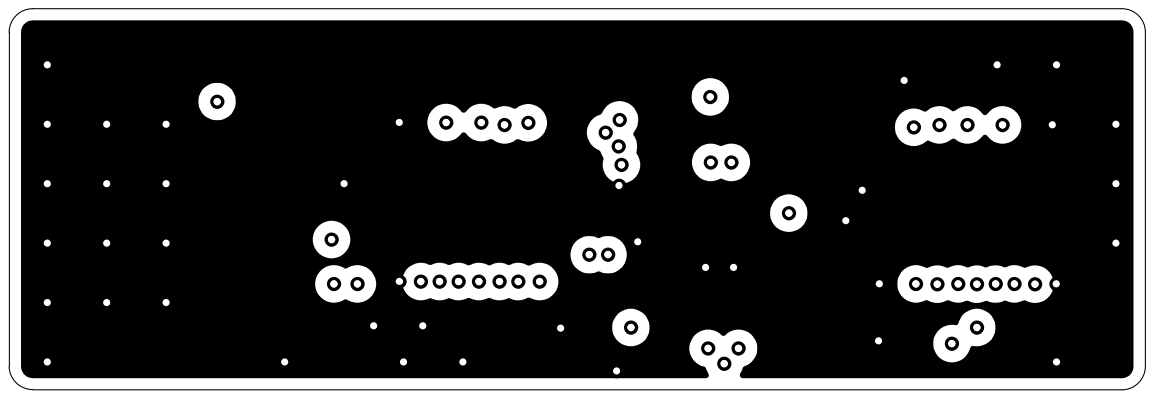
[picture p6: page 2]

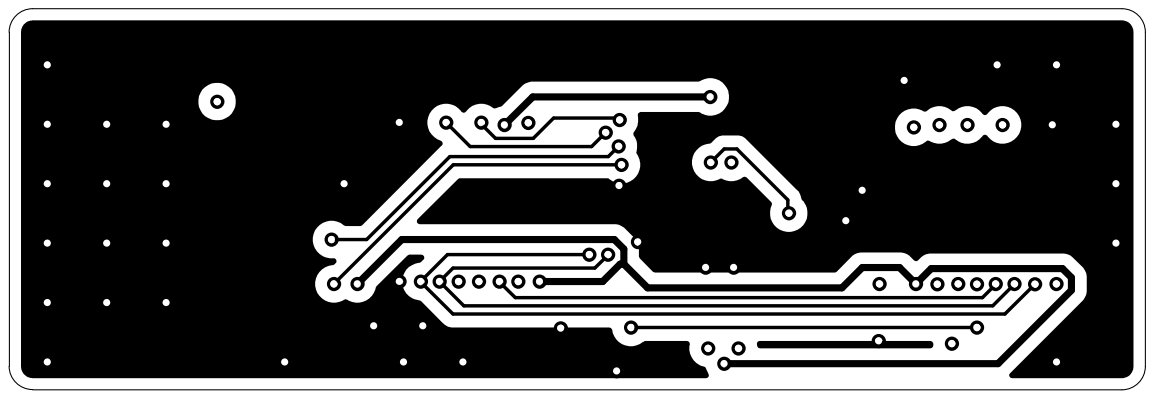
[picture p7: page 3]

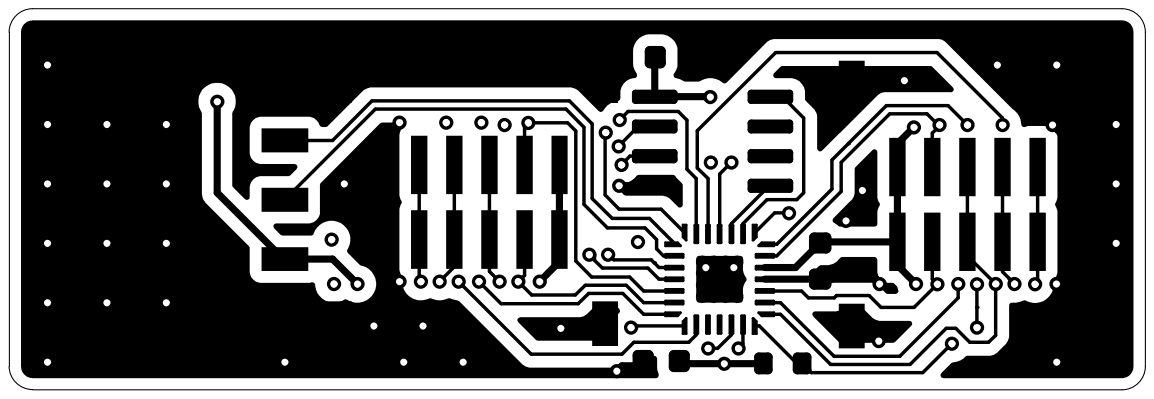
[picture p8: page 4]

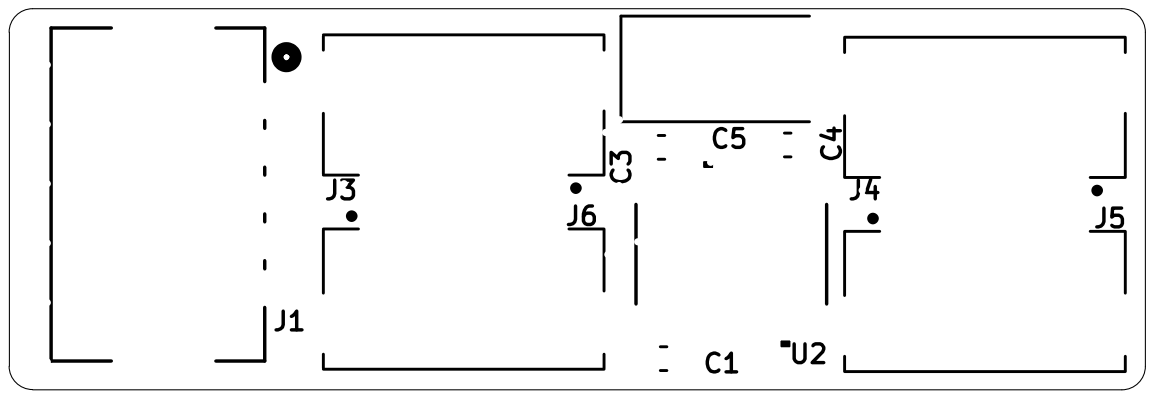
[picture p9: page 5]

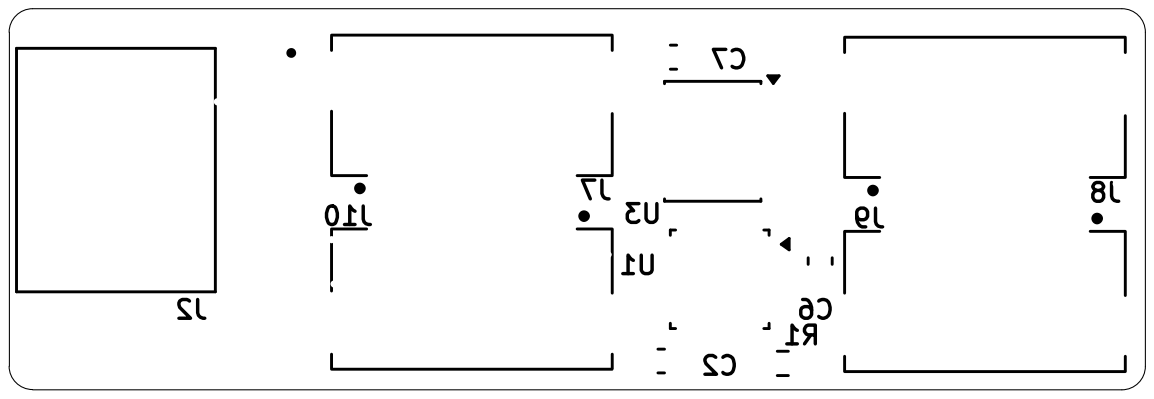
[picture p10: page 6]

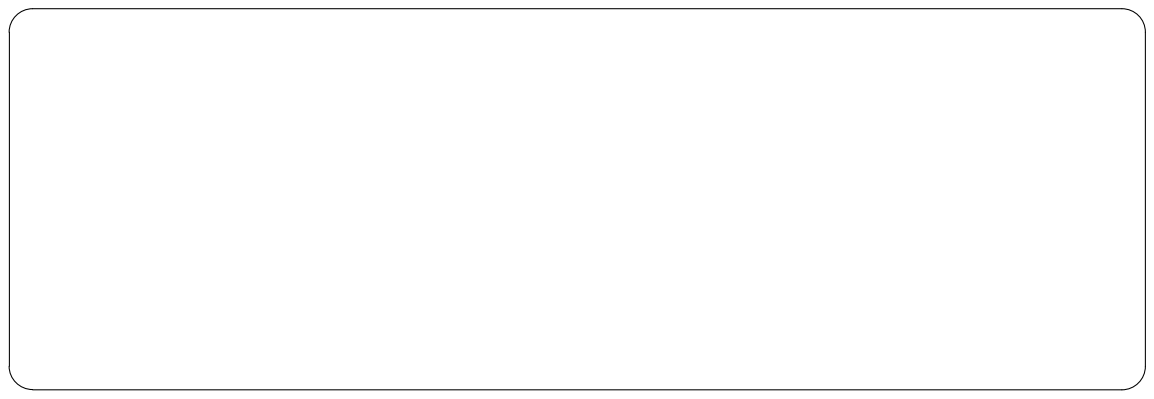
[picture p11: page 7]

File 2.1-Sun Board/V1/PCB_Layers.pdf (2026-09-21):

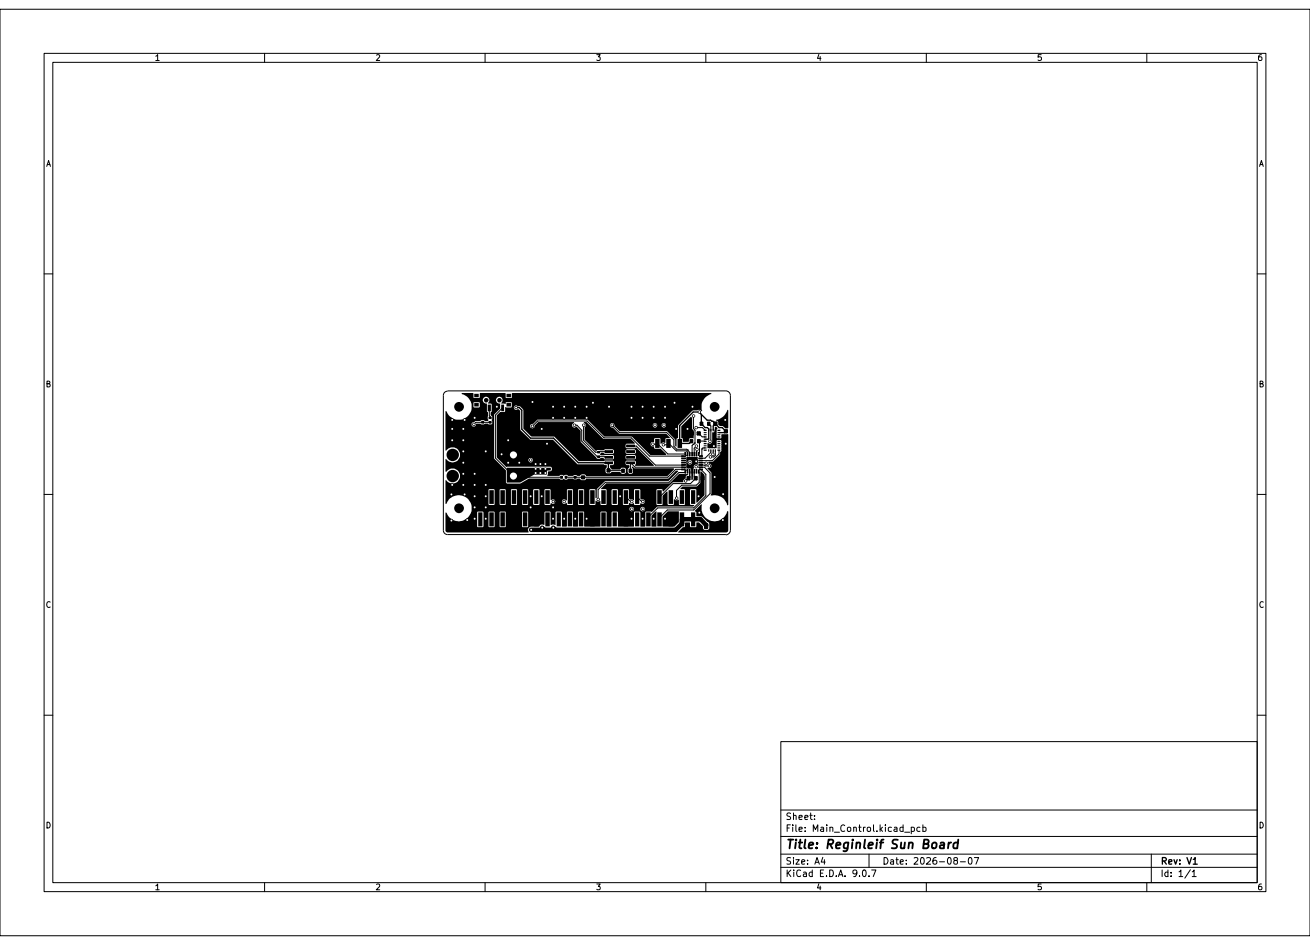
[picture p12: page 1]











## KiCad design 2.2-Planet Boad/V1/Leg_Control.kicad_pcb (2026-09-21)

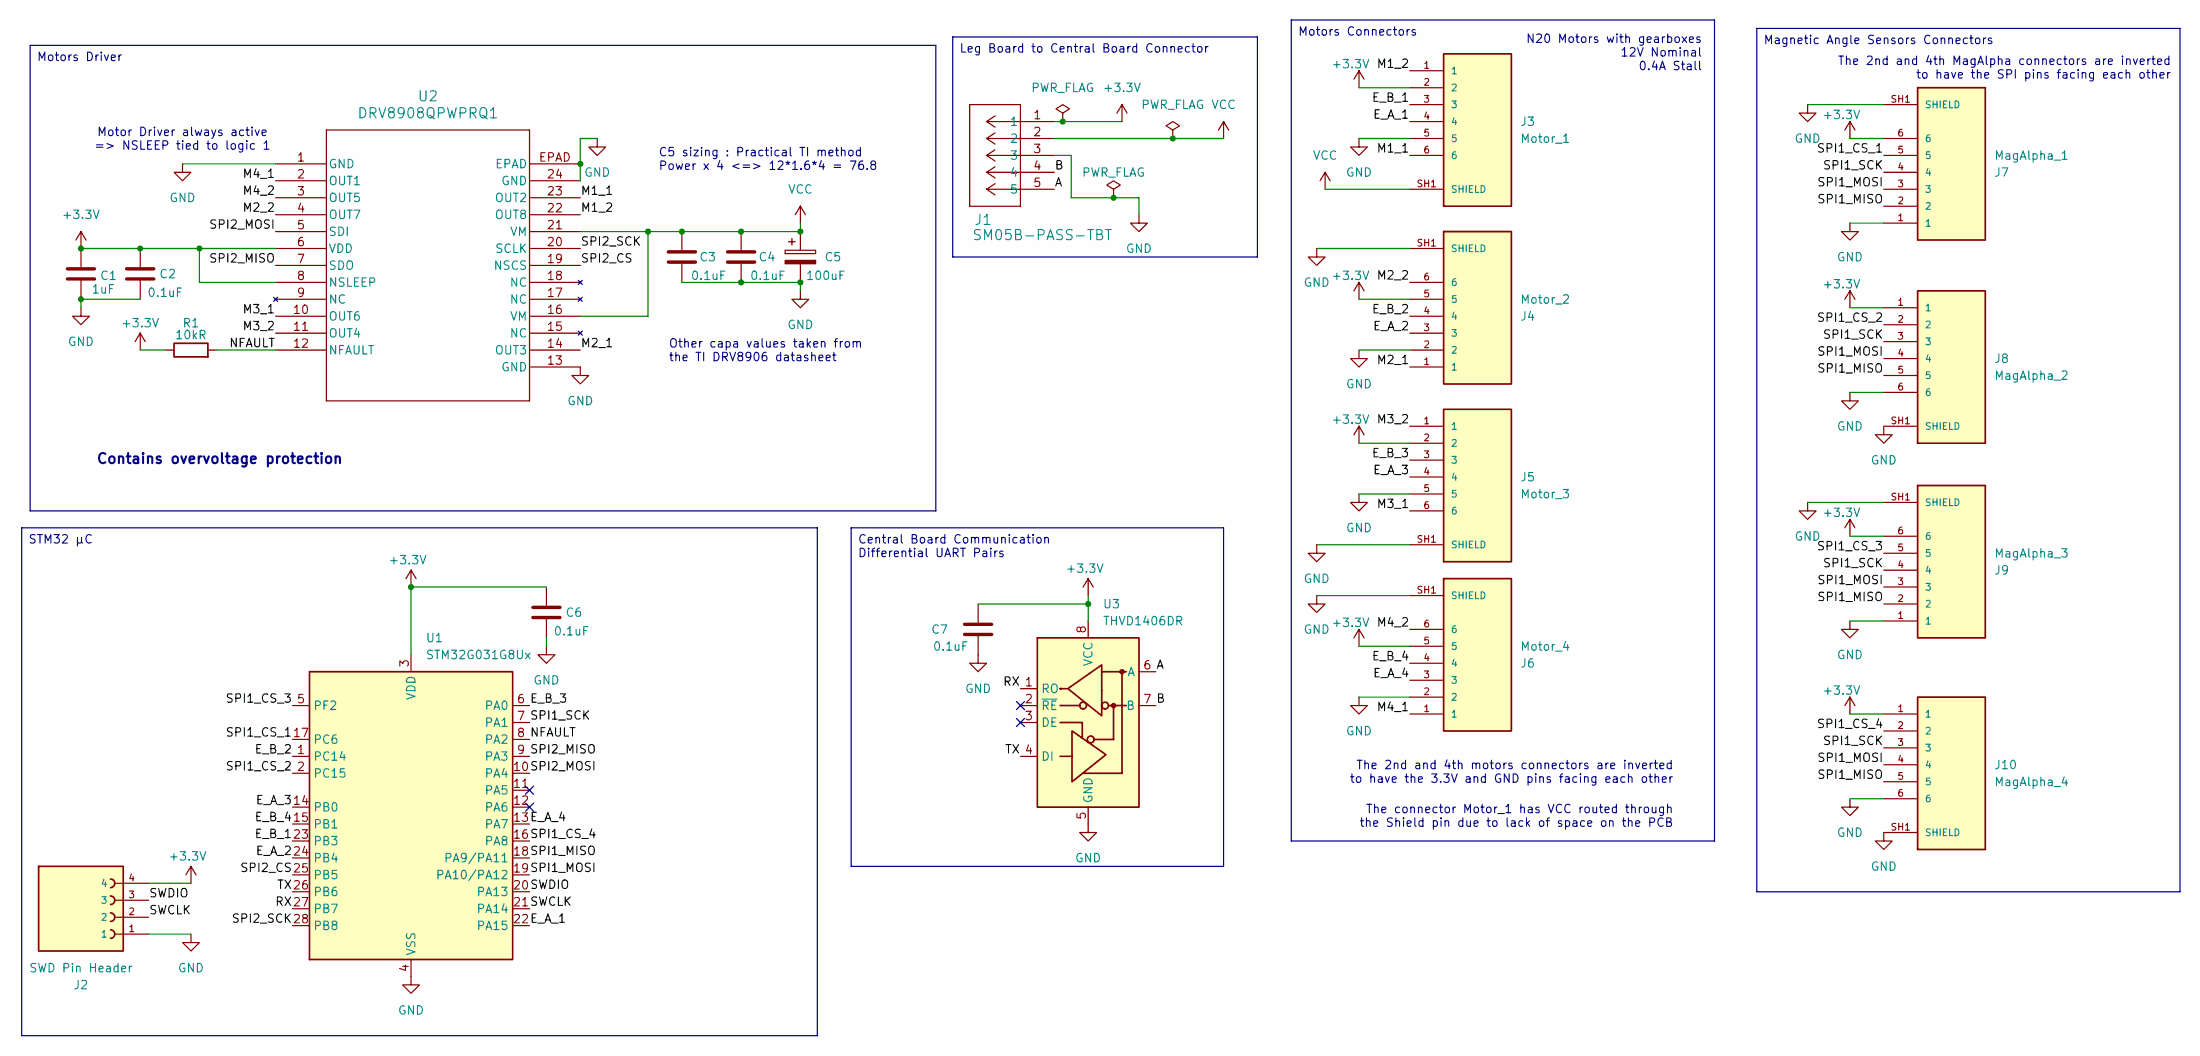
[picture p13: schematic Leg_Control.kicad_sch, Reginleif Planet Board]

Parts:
C1: 1uF; C_0603_1608Metric
C2, C3, C4, C6, C7: 0.1uF; C_0603_1608Metric
C5: 100uF; CP_EIA-7343-43_Kemet-X
J1: SM05B-PASS-TBT; SM05B_PASS
J2: SWD Pin Header; HARWIN_M20-7910442R
J3: Motor_1; JST_S6B-ZR-SM4A-TF_LF__SN_
J4: Motor_2; JST_S6B-ZR-SM4A-TF_LF__SN_
J5: Motor_3; JST_S6B-ZR-SM4A-TF_LF__SN_
J6: Motor_4; JST_S6B-ZR-SM4A-TF_LF__SN_
J7: MagAlpha_1; JST_S6B-ZR-SM4A-TF_LF__SN_
J8: MagAlpha_2; JST_S6B-ZR-SM4A-TF_LF__SN_
J9: MagAlpha_3; JST_S6B-ZR-SM4A-TF_LF__SN_
J10: MagAlpha_4; JST_S6B-ZR-SM4A-TF_LF__SN_
R1: 10kR; R_0603_1608Metric
U1: STM32G031G8Ux; QFN-28_4x4mm_P0.5mm
U2: DRV8908QPWPRQ1; PWP24_4P5X7P9_TEX-L
U3: THVD1406DR; SOIC-8_3.9x4.9mm_P1.27mm

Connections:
+3.3V: C1.1, C2.1, C6.1, C7.1, J1.1, J2.4, J3.2, J4.5, J5.2, J6.5, J7.6, J8.1, J9.6, J10.1, R1.1, U1.3 (VDD), U2.6 (VDD), U2.8 (NSLEEP), U3.8 (VCC)
/A: J1.5, U3.6 (A)
/B: J1.4, U3.7 (B)
/E_A_1: J3.4, U1.22 (PA15)
/E_A_2: J4.3, U1.24 (PB4)
/E_A_3: J5.4, U1.14 (PB0)
/E_A_4: J6.3, U1.13 (PA7)
/E_B_1: J3.3, U1.23 (PB3)
/E_B_2: J4.4, U1.1 (PC14)
/E_B_3: J5.3, U1.6 (PA0)
/E_B_4: J6.4, U1.15 (PB1)
/M1_1: J3.6, U2.23 (OUT2)
/M1_2: J3.1, U2.22 (OUT8)
/M2_1: J4.1, U2.14 (OUT3)
/M2_2: J4.6, U2.4 (OUT7)
/M3_1: J5.6, U2.10 (OUT6)
/M3_2: J5.1, U2.11 (OUT4)
/M4_1: J6.1, U2.2 (OUT1)
/M4_2: J6.6, U2.3 (OUT5)
/NFAULT: R1.2, U1.8 (PA2), U2.12 (NFAULT)
/RX: U1.27 (PB7), U3.1 (RO)
/SPI1_CS_1: J7.5, U1.17 (PC6)
/SPI1_CS_2: J8.2, U1.2 (PC15)
/SPI1_CS_3: J9.5, U1.5 (PF2)
/SPI1_CS_4: J10.2, U1.16 (PA8)
/SPI1_MISO: J7.2, J8.5, J9.2, J10.5, U1.18 (PA9/PA11)
/SPI1_MOSI: J7.3, J8.4, J9.3, J10.4, U1.19 (PA10/PA12)
/SPI1_SCK: J7.4, J8.3, J9.4, J10.3, U1.7 (PA1)
/SPI2_CS: U1.25 (PB5), U2.19 (NSCS)
/SPI2_MISO: U1.9 (PA3), U2.7 (SDO)
/SPI2_MOSI: U1.10 (PA4), U2.5 (SDI)
/SPI2_SCK: U1.28 (PB8), U2.20 (SCLK)
/SWCLK: J2.2, U1.21 (PA14)
/SWDIO: J2.3, U1.20 (PA13)
/TX: U1.26 (PB6), U3.4 (DI)
GND: C1.2, C2.2, C3.2, C4.2, C5.2, C6.2, C7.2, J1.3, J2.1, J3.5, J4.2, J4.SH1 (SHIELD), J4.SH2 (SHIELD), J5.5, J5.SH1 (SHIELD), J5.SH2 (SHIELD), J6.2, J6.SH1 (SHIELD), J6.SH2 (SHIELD), J7.1, J7.SH1 (SHIELD), J7.SH2 (SHIELD), J8.6, J8.SH1 (SHIELD), J8.SH2 (SHIELD), J9.1, J9.SH1 (SHIELD), J9.SH2 (SHIELD), J10.6, J10.SH1 (SHIELD), J10.SH2 (SHIELD), U1.4 (VSS), U2.1 (GND), U2.13 (GND), U2.24 (GND), U2.EPAD, U3.5 (GND)
VCC: C3.1, C4.1, C5.1, J1.2, J3.SH1 (SHIELD), J3.SH2 (SHIELD), U2.16 (VM), U2.21 (VM)

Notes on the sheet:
N20 Motors with gearboxes 12V Nominal 0.4A Stall
Motor Driver always active => NSLEEP tied to logic 1
The connector Motor_1 has VCC routed through the Shield pin due to lack of space on the PCB
Other capa values taken from the TI DRV8906 datasheet
The 2nd and 4th MagAlpha connectors are inverted to have the SPI pins facing each other
The 2nd and 4th motors connectors are inverted to have the 3.3V and GND pins facing each other
Contains overvoltage protection
C5 sizing : Practical TI method Power x 4 <=> 12*1.6*4 = 76.8
Magnetic Angle Sensors Connectors
Central Board Communication Differential UART Pairs
STM32 µC
Motors Driver
Leg Board to Central Board Connector
Motors Connectors

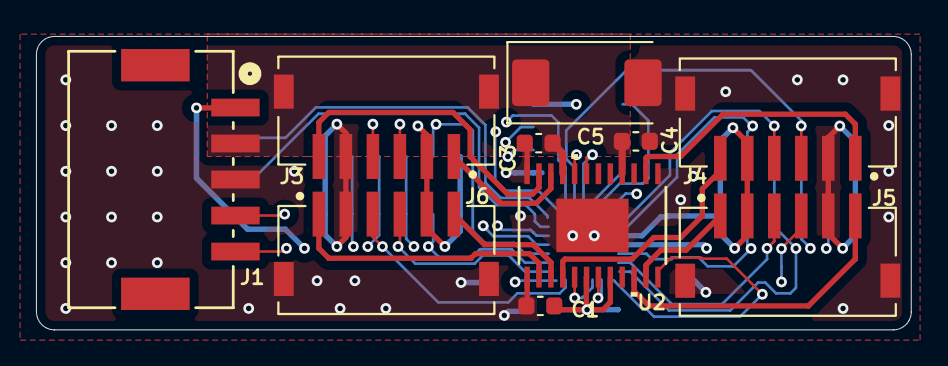
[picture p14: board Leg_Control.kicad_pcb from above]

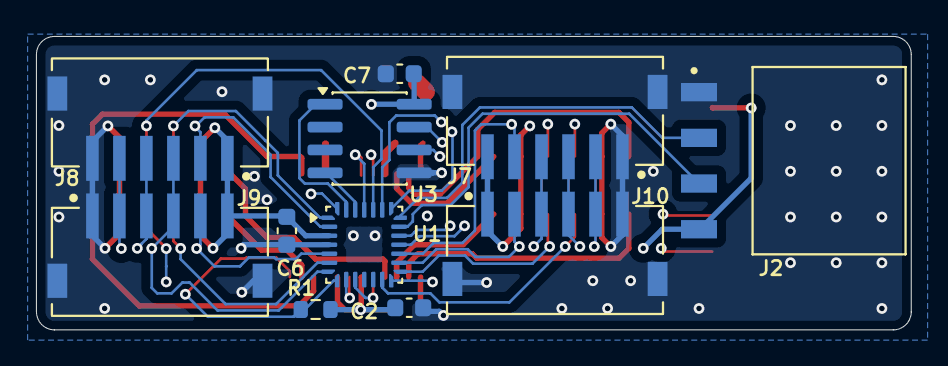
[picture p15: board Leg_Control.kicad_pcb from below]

Board: 4 copper layers, 48.6 x 16.3 mm, 21 parts (11 on the bottom side), 37 nets.

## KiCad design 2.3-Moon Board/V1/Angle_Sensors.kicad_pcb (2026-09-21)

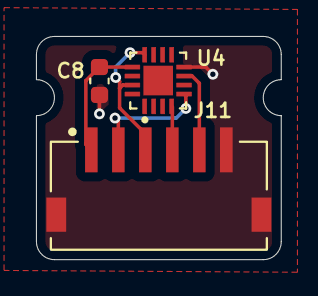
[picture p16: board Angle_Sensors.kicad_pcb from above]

Board: 4 copper layers, 13.6 x 12.4 mm, 3 parts (0 on the bottom side), 6 nets.

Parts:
C8: 1uF; C_0603_1608Metric
J11: S6B-ZR-SM4-TF; JST_S6B-ZR-SM4A-TF_LF__SN_
U4: MA730GQ-Z_1; QFN50P300X300X100-17N

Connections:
+3.3V: C8.1, J11.1, U4.13 (VDD)
GND: C8.2, J11.6, J11.SH1 (SHIELD), J11.SH2 (SHIELD), U4.8 (GND)
unnamed: J11.2, U4.5 (CS)
unnamed: J11.5, U4.7 (MISO)
unnamed: J11.4, U4.4 (MOSI)
unnamed: J11.3, U4.12 (SCLK), U4.15 (SSCK)

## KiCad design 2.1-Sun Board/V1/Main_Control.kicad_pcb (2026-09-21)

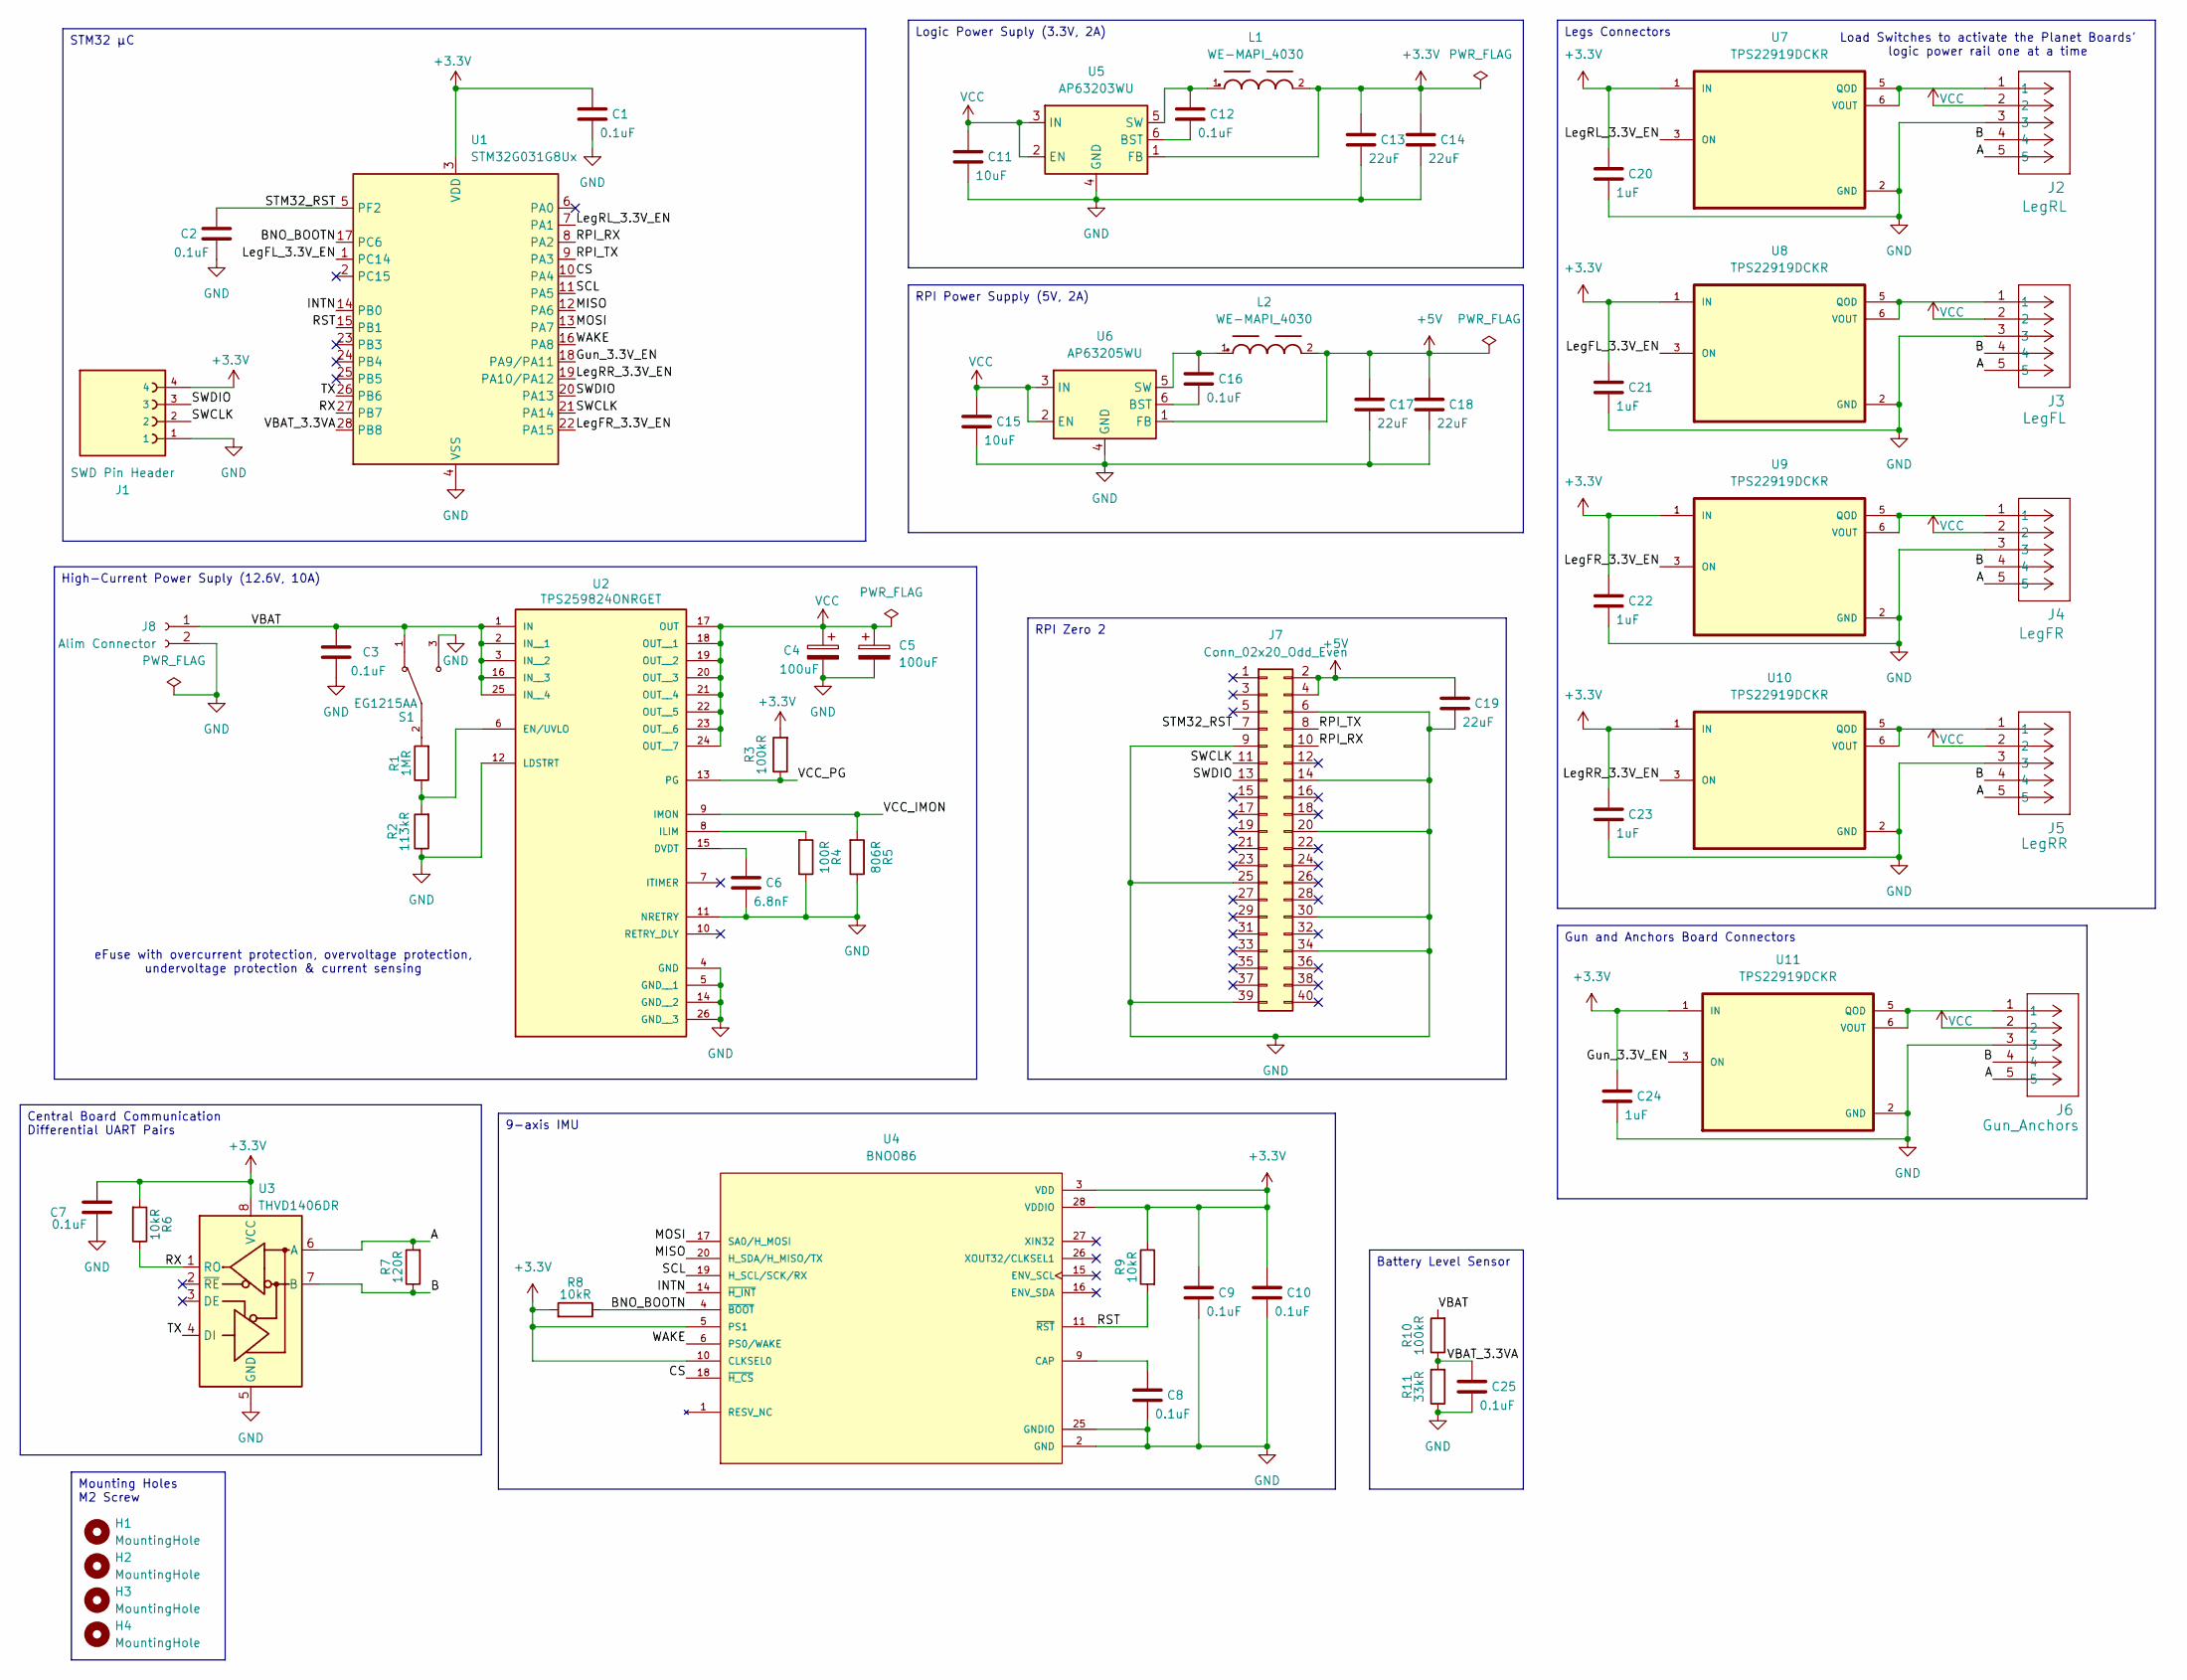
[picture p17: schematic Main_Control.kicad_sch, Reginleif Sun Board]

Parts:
C1, C2, C3, C7, C8, C9, C10, C12, C16, C25: 0.1uF; C_0603_1608Metric
C4, C5: 100uF; CP_EIA-7343-43_Kemet-X
C6: 6.8nF; C_0402_1005Metric
C11, C15: 10uF; C_0603_1608Metric
C13, C14, C17, C18: 22uF; C_0805_2012Metric
C19: 22uF; R_0805_2012Metric
C20, C21, C22, C23, C24: 1uF; C_0402_1005Metric
H1, H2, H3, H4: MountingHole; MountingHole_2.2mm_M2
J1: SWD Pin Header; HARWIN_M20-7910442R
J2: LegRL; SM05B_PASS
J3: LegFL; SM05B_PASS
J4: LegFR; SM05B_PASS
J5: LegRR; SM05B_PASS
J6: Gun_Anchors; SM05B_PASS
J7: Conn_02x20_Odd_Even; PinHeader_2x20_P2.54mm_Vertical_SMD
J8: Alim Connector; SolderWire-0.75sqmm_1x02_P4.8mm_D1.25mm_OD2.3mm_Relief
L1, L2: WE-MAPI_4030
R1: 1MR; R_0402_1005Metric
R2: 113kR; R_0402_1005Metric
R3, R10: 100kR; R_0402_1005Metric
R4: 100R; R_0402_1005Metric
R5: 806R; R_0402_1005Metric
R6, R8, R9: 10kR; R_0603_1608Metric
R7: 120R; R_0402_1005Metric
R11: 33kR; R_0402_1005Metric
S1: EG1215AA; SW_EG1215AA; PARTREV A
U1: STM32G031G8Ux; QFN-28_4x4mm_P0.5mm
U2: TPS259824ONRGET; IC_TPS259824ONRGET; Part_Rev C
U3: THVD1406DR; SOIC-8_3.9x4.9mm_P1.27mm
U4: BNO086; IC_BNO086; PARTREV v1.17
U5: AP63203WU; TSOT-23-6
U6: AP63205WU; TSOT-23-6
U7, U8, U9, U10, U11: TPS22919DCKR; SOT65P210X110-6N

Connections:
+3.3V: C1.1, C7.1, C9.1, C10.1, C13.1, C14.1, C20.1, C21.1, C22.1, C23.1, C24.1, J1.4, L1.2, R3.2, R6.2, R8.2, R9.1, U1.3 (VDD), U3.8 (VCC), U4.3 (VDD), U4.5 (PS1), U4.10 (CLKSEL0), U4.28 (VDDIO), U5.1 (FB), U7.1 (IN), U8.1 (IN), U9.1 (IN), U10.1 (IN), U11.1 (IN)
+5V: C17.1, C18.1, C19.1, J7.2, J7.4, L2.2, U6.1 (FB)
/A: J2.5, J3.5, J4.5, J5.5, J6.5, R7.2, U3.6 (A)
/B: J2.4, J3.4, J4.4, J5.4, J6.4, R7.1, U3.7 (B)
/BNO_BOOTN: R8.1, U1.17 (PC6), U4.4 (~BOOT)
/CS: U1.10 (PA4), U4.18 (~H_CS)
/Gun_3.3V_EN: U1.18 (PA9/PA11), U11.3 (ON)
/INTN: U1.14 (PB0), U4.14 (~H_INT)
/LegFL_3.3V_EN: U1.1 (PC14), U8.3 (ON)
/LegFR_3.3V_EN: U1.22 (PA15), U9.3 (ON)
/LegRL_3.3V_EN: U1.7 (PA1), U7.3 (ON)
/LegRR_3.3V_EN: U1.19 (PA10/PA12), U10.3 (ON)
/MISO: U1.12 (PA6), U4.20 (H_SDA/H_MISO/TX)
/MOSI: U1.13 (PA7), U4.17 (SA0/H_MOSI)
/RPI_RX: J7.10, U1.8 (PA2)
/RPI_TX: J7.8, U1.9 (PA3)
/RST: R9.2, U1.15 (PB1), U4.11 (~RST)
/RX: R6.1, U1.27 (PB7), U3.1 (RO)
/SCL: U1.11 (PA5), U4.19 (H_SCL/SCK/RX)
/STM32_RST: C2.1, J7.7, U1.5 (PF2)
/SWCLK: J1.2, J7.11, U1.21 (PA14)
/SWDIO: J1.3, J7.13, U1.20 (PA13)
/TX: U1.26 (PB6), U3.4 (DI)
/VBAT: C3.1, J8.1, R10.2, S1.1, U2.1 (IN), U2.2 (IN__1), U2.3 (IN__2), U2.16 (IN__3), U2.25 (IN__4), U2.27, U2.28, U2.29, U2.30, U2.31, U2.32
/VBAT_3.3VA: C25.1, R10.1, R11.2, U1.28 (PB8)
/VCC_IMON: R5.2, U2.9 (IMON)
/VCC_PG: R3.1, U2.13 (PG)
/WAKE: U1.16 (PA8), U4.6 (PS0/WAKE)
GND: C1.2, C2.2, C3.2, C4.2, C5.2, C6.2, C7.2, C8.2, C9.2, C10.2, C11.2, C13.2, C14.2, C15.2, C17.2, C18.2, C19.2, C20.2, C21.2, C22.2, C23.2, C24.2, C25.2, J1.1, J2.3, J3.3, J4.3, J5.3, J6.3, J7.6, J7.9, J7.14, J7.20, J7.25, J7.30, J7.34, J7.39, J8.2, R2.1, R4.1, R5.1, R11.1, S1.3, U1.4 (VSS), U2.4 (GND), U2.5 (GND__1), U2.11 (NRETRY), U2.12 (LDSTRT), U2.14 (GND__2), U2.26 (GND__3), U2.33, U2.34, U2.35, U3.5 (GND), U4.2 (GND), U4.25 (GNDIO), U5.4 (GND), U6.4 (GND), U7.2 (GND), U8.2 (GND), U9.2 (GND), U10.2 (GND), U11.2 (GND)
unnamed: R1.2, S1.2
unnamed: C6.1, U2.15 (DVDT)
unnamed: R1.1, R2.2, U2.6 (EN/UVLO)
unnamed: R4.2, U2.8 (ILIM)
unnamed: C8.1, U4.9 (CAP)
unnamed: C12.2, U5.6 (BST)
unnamed: C12.1, L1.1, U5.5 (SW)
unnamed: C16.2, U6.6 (BST)
unnamed: C16.1, L2.1, U6.5 (SW)
unnamed: J2.1, U7.5 (QOD), U7.6 (VOUT)
unnamed: J3.1, U8.5 (QOD), U8.6 (VOUT)
unnamed: J4.1, U9.5 (QOD), U9.6 (VOUT)
unnamed: J5.1, U10.5 (QOD), U10.6 (VOUT)
unnamed: J6.1, U11.5 (QOD), U11.6 (VOUT)
VCC: C4.1, C5.1, C11.1, C15.1, J2.2, J3.2, J4.2, J5.2, J6.2, U2.17 (OUT), U2.18 (OUT__1), U2.19 (OUT__2), U2.20 (OUT__3), U2.21 (OUT__4), U2.22 (OUT__5), U2.23 (OUT__6), U2.24 (OUT__7), U5.2 (EN), U5.3 (IN), U6.2 (EN), U6.3 (IN)

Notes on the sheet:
Load Switches to activate the Planet Boards' logic power rail one at a time
eFuse with overcurrent protection, overvoltage protection, undervoltage protection & current sensing
STM32 µC
RPI Power Supply (5V, 2A)
Legs Connectors
Mounting Holes M2 Screw
Gun and Anchors Board Connectors
Logic Power Suply (3.3V, 2A)
Central Board Communication Differential UART Pairs
9-axis IMU
High-Current Power Suply (12.6V, 10A)
Battery Level Sensor
RPI Zero 2

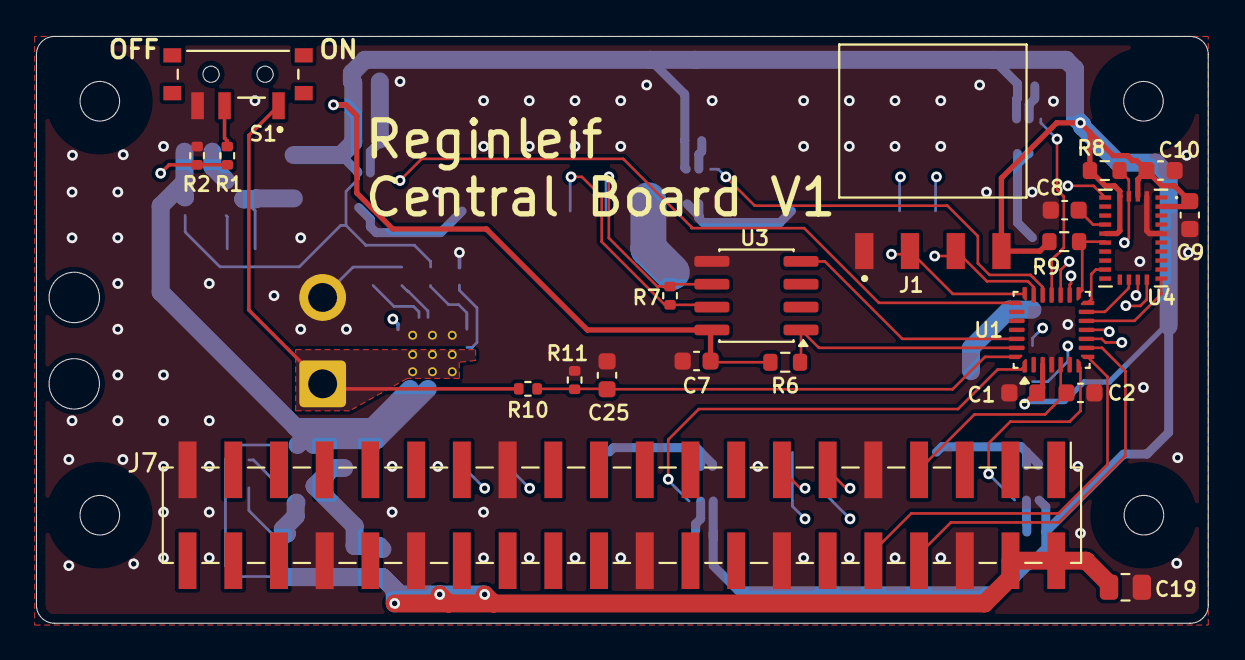
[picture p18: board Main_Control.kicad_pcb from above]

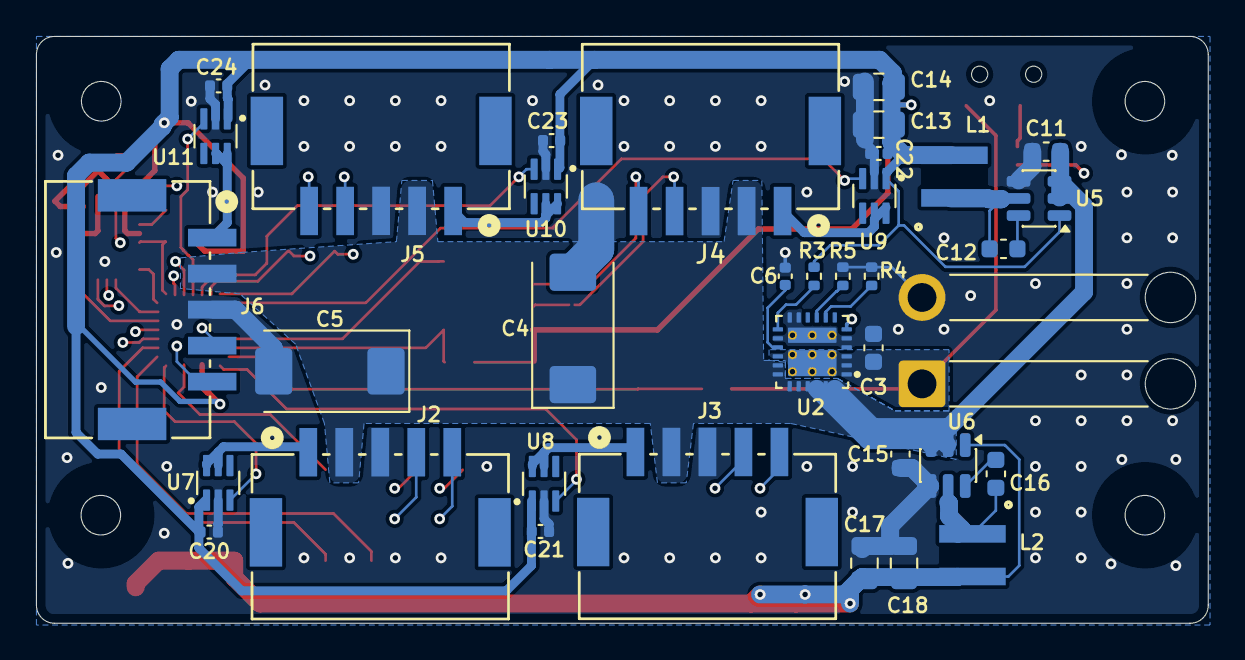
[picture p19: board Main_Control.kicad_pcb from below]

Board: 4 copper layers, 65.1 x 32.6 mm, 62 parts (36 on the bottom side), 44 nets.

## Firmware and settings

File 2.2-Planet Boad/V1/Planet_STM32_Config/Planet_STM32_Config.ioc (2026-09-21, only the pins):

Mcu.UserName=STM32G031G8Ux
PA0.GPIO_Label=E_3_B
PA0.Signal=GPXTI0
PA1.Signal=SPI1_SCK
PA13.Signal=SYS_SWDIO
PA14-BOOT0.Signal=SYS_SWCLK
PA15.GPIO_Label=E_1_A
PA15.Signal=GPIO_Input
PA2.GPIO_Label=NFAULT
PA2.Signal=GPXTI2
PA3.Signal=SPI2_MISO
PA4.Signal=SPI2_MOSI
PA7.GPIO_Label=E_4_A
PA7.Signal=GPIO_Input
PA8.GPIO_Label=SPI1_CS_4
PA8.Signal=GPIO_Output
PB0.GPIO_Label=E_3_A
PB0.Signal=GPIO_Input
PB1.GPIO_Label=E_4_B
PB1.Signal=GPXTI1
PB3.GPIO_Label=E_1_B
PB3.Signal=GPXTI3
PB4.GPIO_Label=E_2_A
PB4.Signal=GPIO_Input
PB5.GPIO_Label=SPI2_CS
PB5.Signal=GPIO_Output
PB6.Signal=USART1_TX
PB7.Signal=USART1_RX
PB8.Signal=SPI2_SCK
PC6.GPIO_Label=SPI1_CS_1
PC6.Signal=GPIO_Output

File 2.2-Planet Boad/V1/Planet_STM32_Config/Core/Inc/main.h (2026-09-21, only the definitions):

#define E_2_B_Pin GPIO_PIN_14
#define E_2_B_GPIO_Port GPIOC
#define E_2_B_EXTI_IRQn EXTI4_15_IRQn
#define SPI1_CS_2_Pin GPIO_PIN_15
#define SPI1_CS_2_GPIO_Port GPIOC
#define SPI1_CS_3_Pin GPIO_PIN_2
#define SPI1_CS_3_GPIO_Port GPIOF
#define E_3_B_Pin GPIO_PIN_0
#define E_3_B_GPIO_Port GPIOA
#define E_3_B_EXTI_IRQn EXTI0_1_IRQn
#define NFAULT_Pin GPIO_PIN_2
#define NFAULT_GPIO_Port GPIOA
#define NFAULT_EXTI_IRQn EXTI2_3_IRQn
#define E_4_A_Pin GPIO_PIN_7
#define E_4_A_GPIO_Port GPIOA
#define E_3_A_Pin GPIO_PIN_0
#define E_3_A_GPIO_Port GPIOB
#define E_4_B_Pin GPIO_PIN_1
#define E_4_B_GPIO_Port GPIOB
#define E_4_B_EXTI_IRQn EXTI0_1_IRQn
#define SPI1_CS_4_Pin GPIO_PIN_8
#define SPI1_CS_4_GPIO_Port GPIOA
#define SPI1_CS_1_Pin GPIO_PIN_6
#define SPI1_CS_1_GPIO_Port GPIOC
#define E_1_A_Pin GPIO_PIN_15
#define E_1_A_GPIO_Port GPIOA
#define E_1_B_Pin GPIO_PIN_3
#define E_1_B_GPIO_Port GPIOB
#define E_1_B_EXTI_IRQn EXTI2_3_IRQn
#define E_2_A_Pin GPIO_PIN_4
#define E_2_A_GPIO_Port GPIOB
#define SPI2_CS_Pin GPIO_PIN_5
#define SPI2_CS_GPIO_Port GPIOB

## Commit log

2026-09-21 First Upload
    General Architecture
    Sun Board V1
    Moon Board V1
    [Angle_Sensors.kicad_pcb, Angle_Sensors.kicad_sch, BOM.xls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]
2026-09-21 Planet Board V1 Upload
    STM32 code still WIP
    [BOM.xls, Leg_Control.kicad_pcb, Leg_Control.kicad_sch]

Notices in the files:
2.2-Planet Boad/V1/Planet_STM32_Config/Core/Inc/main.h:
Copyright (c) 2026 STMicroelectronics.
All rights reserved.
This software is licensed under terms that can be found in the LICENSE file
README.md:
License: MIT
